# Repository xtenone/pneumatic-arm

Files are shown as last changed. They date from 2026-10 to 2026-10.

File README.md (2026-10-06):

# pneumatic-arm

An accessible robot arm that works with cylinders, like muscles, and is controlled with
feedback by a program or AI. Built from ordinary, widely available parts. The end goal
is an arm that picks up blocks of about 15 kg and builds a wall with them.

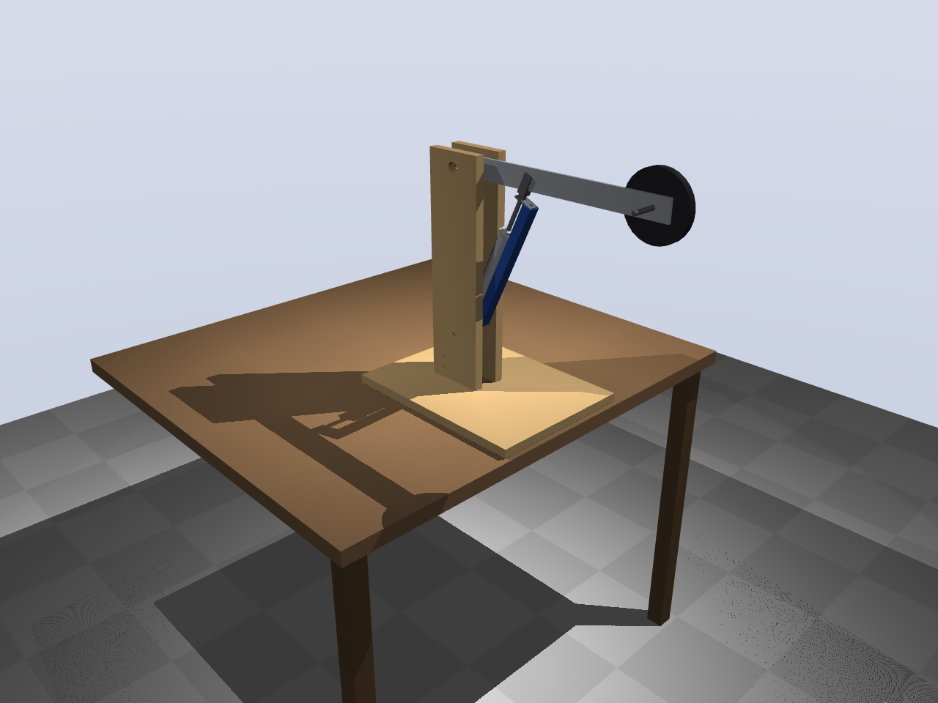
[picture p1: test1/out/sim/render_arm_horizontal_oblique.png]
Test 1


## Status

| Step | Status |
|---|---|
| Goal and requirements | [goal.md](goal.md) |
| **Test 1 — arm with one degree of freedom** | design, CAD, simulation, firmware and manual done; parts ordered, not built yet — [test1/](test1/README.md) |
| Test 1 reference — the same arm on a harmonic drive | sizing done — [test1-harmonic-drive/](test1-harmonic-drive/README.md) |
| Test 1 reference — printed cycloidal drive (PLA) | on hold; designed, STL ready — [test1-cycloid/](test1-cycloid/README.md) |
| 2-DOF joint (shoulder, elbow) | first analysis — [docs/2dof-joint.md](docs/2dof-joint.md) |
| Plan: what is done and what is left | [docs/plan.md](docs/plan.md) |
| Cost per degree of freedom | [docs/cost-per-dof.md](docs/cost-per-dof.md) |
| Full arm — concept render (layout and proportions) | first picture — [full-arm/](full-arm/README.md) |
| Full-size joint: 15 kg at 1 m (cylinders, speed, air) | first sizing — [docs/full-arm-sizing.md](docs/full-arm-sizing.md) |
| Hydraulics as an option (if more force is needed) | parts and prices — [docs/hydraulics.md](docs/hydraulics.md) |

## Build it yourself

Start at [test1/README.md](test1/README.md) and the
[manual](test1/docs/manual.md). All dimensions are in `test1/params.py`;
`python test1/build.py` regenerates the CAD, simulation, firmware settings, drawings and
bill of materials from it.

## Contributing

Questions, measurements, photos of your own build and improvements are welcome through
issues and pull requests. Measurements from tests T0–T7 are especially valuable: they
make the simulation model better.

## License

Copyleft: hardware under **CERN-OHL-S-2.0**, software under **GPL-3.0-or-later**.
See [LICENSE](LICENSE).

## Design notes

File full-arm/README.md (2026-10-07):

# Full arm — concept

A first picture of the complete arm, placing a 15 kg block on a low wall. Simple shapes
only, to show the layout and proportions; the sizes come from
[docs/full-arm-sizing.md](../docs/full-arm-sizing.md). The renders keep both rolls at 0 and
line the block up with the gripper's yaw motor (see "Choice for now"). Not a worked-out
design.

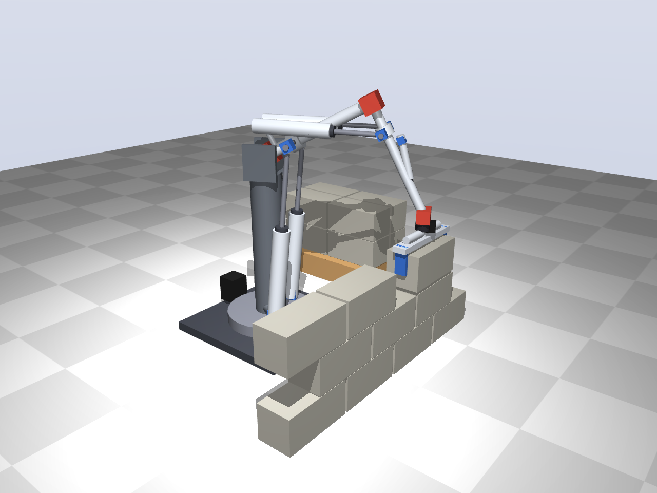
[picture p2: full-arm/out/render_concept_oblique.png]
Concept


## Layout

| Joint | DOF | Drive | Why |
|---|---|---|---|
| Base yaw | 1 | Electric: stepper with belt on a slewing ring | A vertical axis carries no gravity torque, so a small motor is enough, and it can turn further than the ≈ 120° of a cylinder |
| Shoulder | 2 (pitch + roll) | 2 × Ø50 × 300, lever 150 mm (Ø63 in the renders); the [test 2](../test2/README.md) joint at ≈ 1.7× scale | 162 Nm with 15 kg at 1 m (peak), 97 Nm at 0.6 m (work) |
| Elbow | 2 (pitch + forearm roll) | 2 × Ø40–50 lying on top of the upper arm, like a biceps; the same joint as the shoulder | see below |
| Wrist | 1 (pitch) | 1 small cylinder along the forearm | keeps the block level |
| Gripper | — | two jaws closed by a pneumatic cylinder | clamps the block at its ends |

- Upper arm and forearm 0.5 m each, shoulder 0.8 m above the floor, wall 0.6 m in front of
  the base: a low wall of 3 courses, about 1 m wide.
- Cylinders for the heavy joints, a small motor where there is no gravity torque.
- The base yaw axis runs through the shoulder joint, so turning the base does not move the
  shoulder. The column stands behind it on the turntable and turns with it; an arm over the
  top carries the shoulder joint, and the shoulder cylinders' lower pivots sit on a pin
  through the column. The forces of the shoulder cylinders stay inside the column, the
  arm and the upper arm; the arm and the column hanging behind the yaw axis partly
  balance the arm in front of it.

## Elbow: forearm roll instead of a wrist rotation (`python full-arm/elbow.py`)

The elbow uses the same 2-DOF joint as the shoulder. Its roll turns the forearm about its
own axis, as in a human forearm, so the gripper needs no separate rotation. With base
yaw, shoulder pitch + roll, elbow pitch + roll and wrist pitch the arm has 6 DOF: enough
to hold the block level and lined up with the wall.

Required for 9 block positions (3 along the wall, 3 courses), 15 kg block + 3 kg gripper:

| | Range |
|---|---|
| Base yaw | ±41° |
| Shoulder pitch / roll | −7° … +30° / ±20° |
| Elbow pitch | −101° … −64° (forearm steep) |
| Forearm roll | ±42° |
| Wrist pitch | 59° … 78° |
| Elbow cylinders, pin to pin | 454–582 mm (128 mm of stroke used) |
| Elbow cylinder force | ≤ 187 N push: 19% of Ø50, 30% of Ø40 at 5 bar |

- **Feasible.** The shoulder roll stays well within its ±65°; the forearm roll of ±42° just
  fits the ≈ ±45° the elbow allows (see the clash check below).
- The rolls grow with the base yaw: for a wall 1.2 m wide (base yaw ±42° at the ends of a
  wall 0.5 m away) the shoulder needs up to ±86° and the forearm ±69°, beyond the
  joint. For wider walls the base moves along the wall, or the gripper gets its own
  rotation about the vertical (a small motor; no gravity torque there).
- The cylinders lie on top of the upper arm (rear pivots 6 cm from the shoulder, 12 cm
  above the arm axis and 6 cm to the sides, clear of the shoulder hub and its cross
  blocks), on a forearm hub 12 cm from the elbow. A Ø50 × 200 (pin to pin ≈ 390–590 mm)
  covers the lengths.
- Ø40 is enough for the low wall (forearm steep). With the forearm horizontal the elbow
  needs up to ≈ 80 Nm, then Ø50.

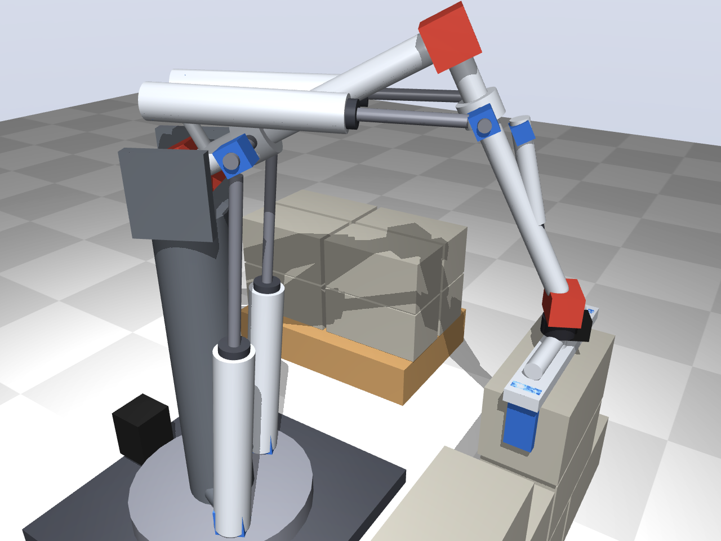
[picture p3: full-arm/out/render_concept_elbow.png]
Elbow


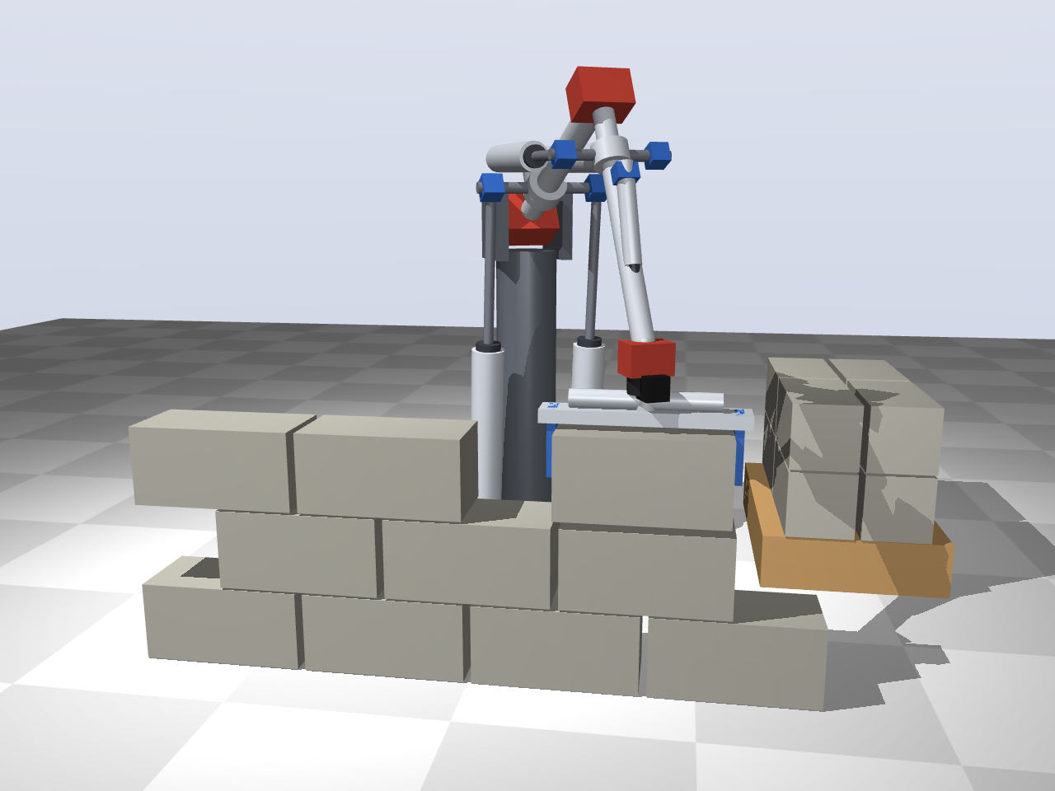
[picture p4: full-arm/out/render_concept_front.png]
Front


### Clash check (`python full-arm/elbow_cad.py`)

CadQuery model of the elbow region in the upper-arm frame: upper arm with the shoulder hub
and its cross blocks, the post with the rear U-joints, the elbow fork and yoke, the forearm
hub with cross blocks, and the two cylinders with rod forks.

| Elbow pitch | Roll 0° | Roll ±42–45° | Roll ±65° |
|---|---|---|---|
| −110° | ok | rod fork touches the forearm hub | many clashes, too short |
| −100° | ok | ok at ±42°, rod fork touches the hub at ±45° | cylinder bodies on the upper arm and shoulder hub |
| −90° … −64° | ok | ok | cylinder bodies on the upper arm and shoulder hub |
| −50° | ok | stroke too short | stroke too short, clashes |

- **The low wall works:** its whole range (pitch −101° … −64°, roll ±42°) is clash-free and
  within the stroke.
- **But the margin is small.** The forearm roll of this layout ends at about ±45°, not the
  ±65° of the shoulder: when rolling, one cylinder dives onto the upper arm and the rod fork
  comes close to the forearm hub.

### Biceps or triceps

The same checks for the cylinders behind the elbow: the forearm shaft sticks out 10 cm
behind the elbow through the joint, with cross blocks 8 cm to the sides; the cylinders lie
high on top of the upper arm and pull that lever, like a triceps or the stick cylinder of
an excavator (`python full-arm/elbow.py triceps`, `python full-arm/elbow_cad.py triceps`).

| | Biceps | Triceps |
|---|---|---|
| Hub on the forearm | 12 cm in front of the elbow | 10 cm behind the elbow |
| Rear pivots | 6 cm from the shoulder, 12 cm up, 6 cm to the sides | 2 cm from the shoulder (post leaning back over the shoulder yoke), 13 cm up, 8 cm to the sides |
| Cylinders | Ø50 × 200 | Ø40 × 200 (shorter: the hub is closer to the rear pivots) |
| Low wall: force | ≤ 187 N push (19% of Ø50) | ≤ 197 N pull (37% of Ø40, 24% of Ø50) |
| Clash-free with roll ±45° | elbow bend 60°–90° (±42° up to 101°) | elbow bend 45°–105° |
| Roll ±65° | cylinder bodies dive onto the upper arm and shoulder hub | only the rod forks touch the small hub at the end of the lever |
| Arm almost straight (bend 30°) | ok | the lever behind the elbow hits the upper arm |

- **Triceps gives the forearm roll more room.** The cylinders never cross the elbow, so they
  cannot dive onto the upper arm when rolling; what is left at ±65° is the hub at the end
  of the lever, which is a detail.
- **Costs of the triceps:** the cylinders pull (smaller annulus area, so Ø50 rather than
  Ø40 once the forearm has to be held horizontal), the forearm shaft has to pass through
  the elbow joint, and the arm cannot be stretched straight.

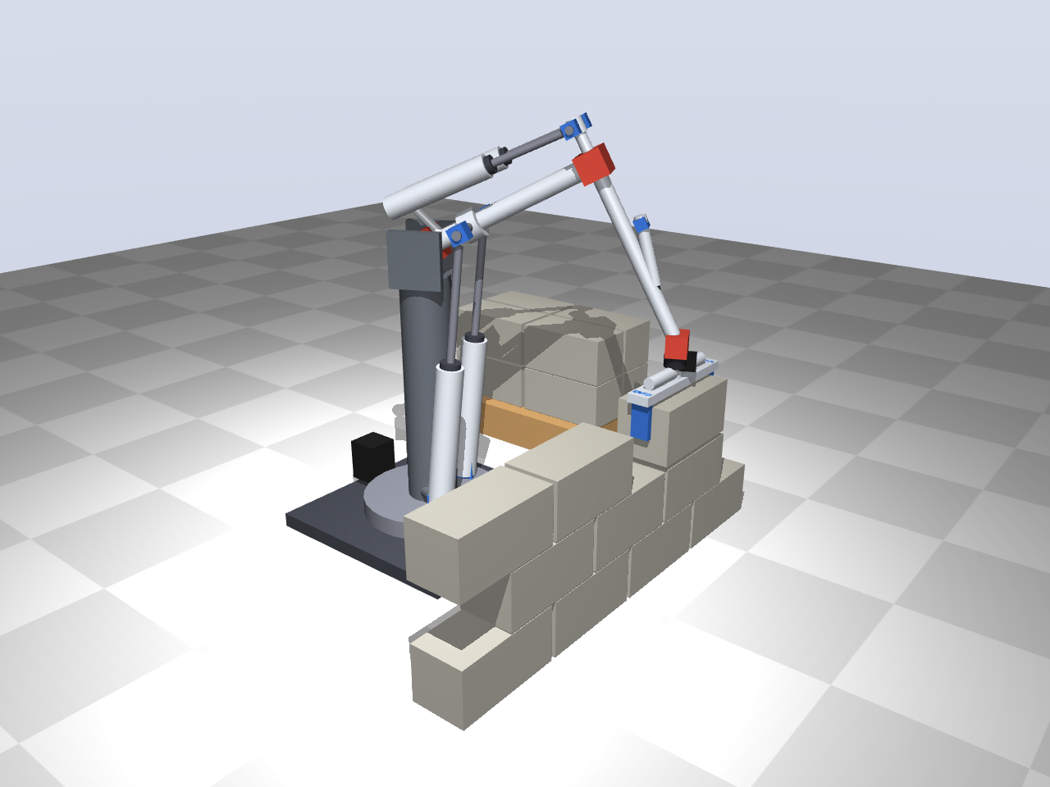
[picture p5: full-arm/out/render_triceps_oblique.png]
Triceps


### Arm turned over: elbow below the shoulder (`python full-arm/elbow.py triceps_down`)

Like a human arm: the upper arm hangs down from the shoulder, the forearm points forward,
and the cylinders behind the upper arm push the lever behind the elbow to lift. Shoulder
at 0.8 m, same low wall.

| | Elbow up, biceps | Elbow down, triceps pushing |
|---|---|---|
| Elbow cylinders | push, ≤ 187 N (19% of Ø50) | push, ≤ 400 N (41% of Ø50): the forearm reaches forward, so the elbow carries more |
| Shoulder pitch | −7° … +30° (the test 2 shoulder layout) | −78° … −49°: the shoulder cylinders need a different layout |
| Shoulder torque | up to 162 Nm (arm stretched forward) | ≤ 128 Nm (upper arm hangs) |
| Block lined up with the wall | 9/9 positions with rolls ≤ ±60° | 3/9: only straight ahead; at ±0.3 m the shoulder roll needs up to ±84° |

- With the forearm roughly horizontal, the forearm roll tilts the block instead of turning
  it. Lining the block up then has to come from the shoulder roll (as the human shoulder
  does), and that needs more than the ±65° of the cross block joint.
- Elbow down therefore needs a gripper that turns about the vertical (a small motor, no
  gravity torque there), or a base that moves along the wall. The forearm roll then tilts
  the tool, which is useful for wiping.

## Holding a glass

A lighter job for the same arm: holding a glass of water just above a table (rolls at 0,
the gripper's yaw motor keeps the jaws square to the arm). Shoulder pitch 64°, elbow −90°.

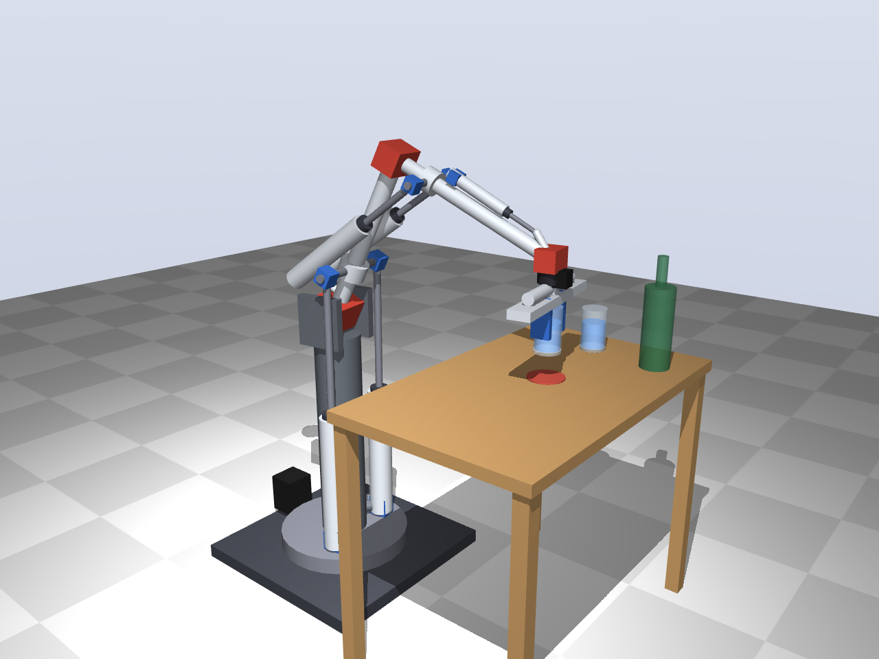
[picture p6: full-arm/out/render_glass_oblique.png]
Glass


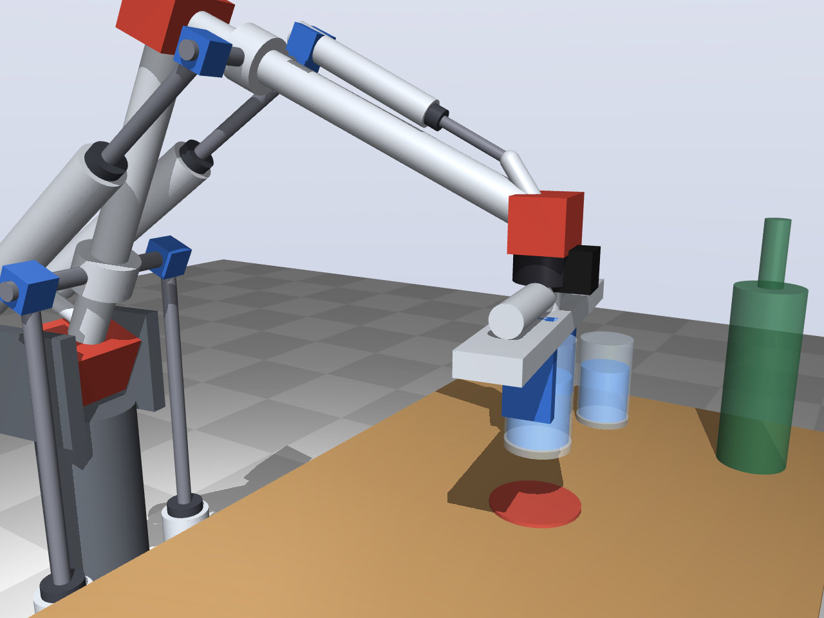
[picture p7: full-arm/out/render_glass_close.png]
Glass, close


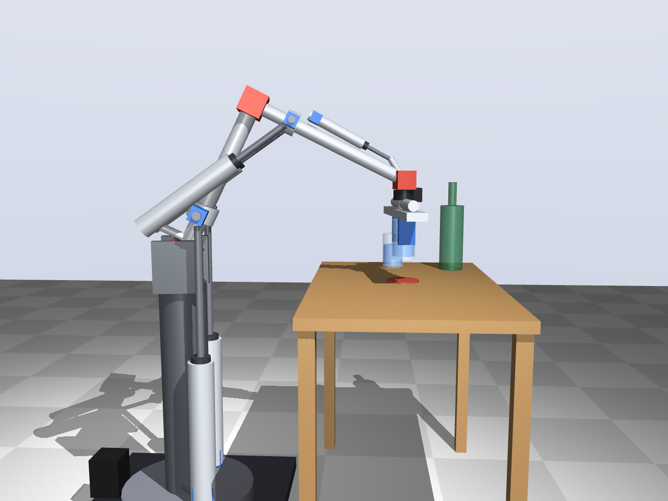
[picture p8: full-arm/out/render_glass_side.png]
Glass, side


The same with the upper arm hanging down (shoulder at 1.15 m, elbow cylinders behind the
upper arm, 60 mm from it and 20 cm from the shoulder: compact Ø50 × 100 cylinders, 22–30 cm pin
to pin, pushing a 9 cm lever behind the elbow; elbow range 10–90°). Render only; the shoulder cylinders are
still drawn in the test 2 layout, which does not suit this posture.

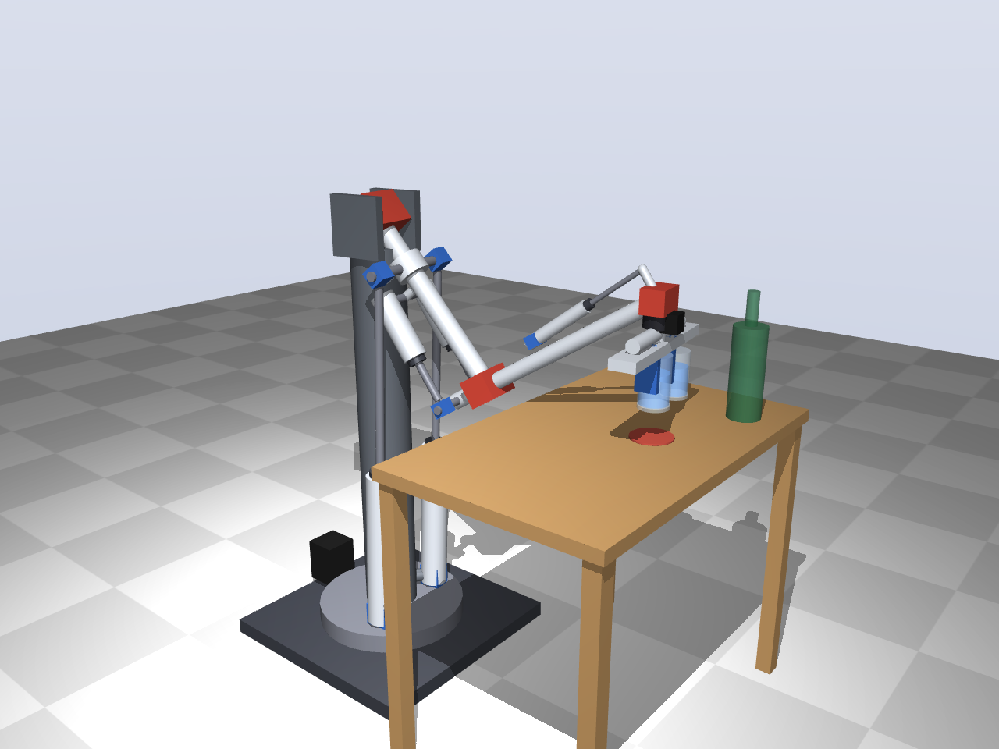
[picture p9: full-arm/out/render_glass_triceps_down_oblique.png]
Glass, upper arm down


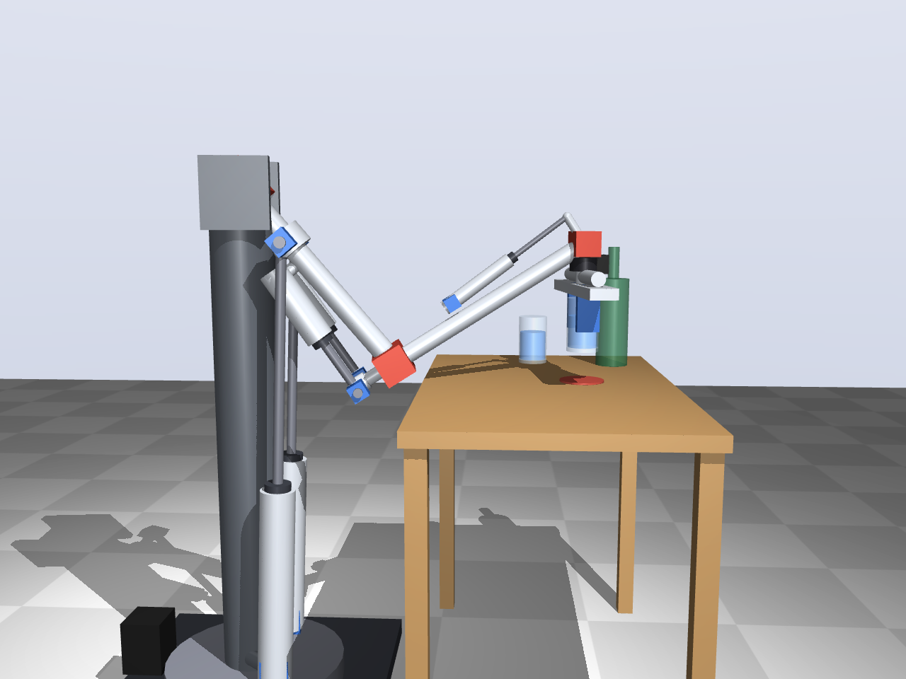
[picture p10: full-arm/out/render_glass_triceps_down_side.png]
Glass, upper arm down, side


## Cocktail impression (`python full-arm/cocktail.py`)

A light version of the arm (upper arm hanging, shoulder at 1.28 m; Ø25 × 80 elbow cylinders
beside the upper arm on a 5 cm lever, elbow 10–120°; wrist and gripper turned by small
motors) makes a cocktail: three bottles poured into a glass, stirred with a bar spoon, glass
slid forward. Kinematic only, 49 s; the video is not kept in git (`--stills` for frames).

The shoulder cylinders lean back to the column behind the shoulder on purpose: they push a
hub 15 cm along the upper arm, and the lever they act on is that line, not the vertical.
Over the video (upper arm −91° … −52°) their lever is 121–150 mm, largest where the arm
reaches furthest forward and gravity pulls hardest; peak force about 124 N. Cylinders
standing vertically under the shoulder would be nearly in line with the hanging upper arm:
lever 31–137 mm, peak force about 330 N.

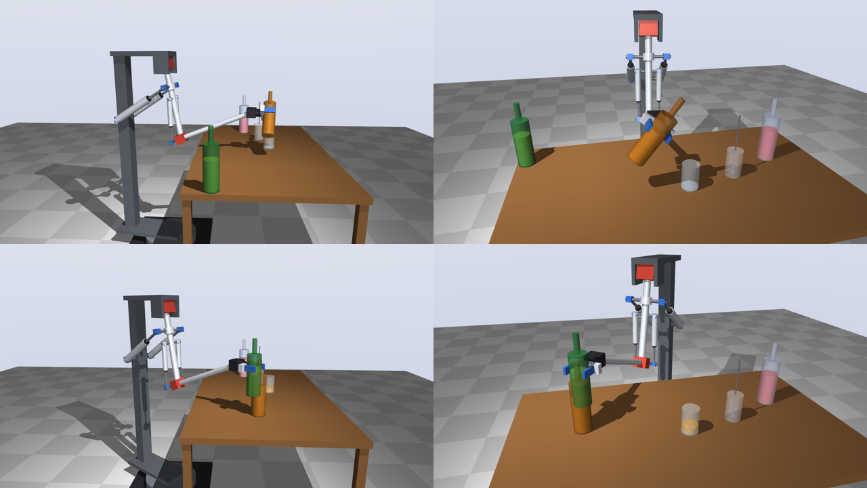
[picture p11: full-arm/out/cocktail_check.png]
Cocktail


## Small wall: start of stage 1 (`python full-arm/small_wall.py`)

The intermediate goal of [docs/small-wall.md](../docs/small-wall.md): the light arm
(shoulder 0.66 m above the table, 2 × Ø32 on a 100 mm lever) with four wooden blocks in a
corner jig and the taped places of the row against a stop strip. The gripper points down
(wrist motor) and is the proposed parallel gripper. `--check` lists the joint angles of
every pick and place: elbow bend 83–101°, base yaw −70° … +22°, shoulder cylinders
248–267 mm pin to pin with a lever of 94–99 mm.

`--video` renders stage 1a (speeds of the heavy arm: 58 s, about 14 s per block) and
`--video --fast` stage 1b (light arm's own speed: 25 s, about 6 s per block). Kinematic
only; the videos are not kept in git.

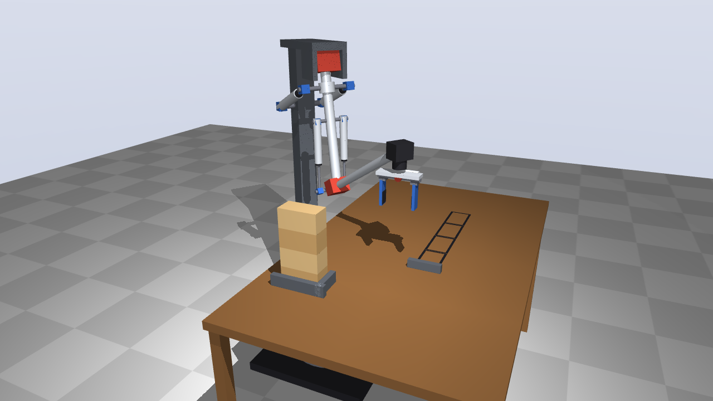
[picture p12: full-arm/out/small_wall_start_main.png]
Small wall, start


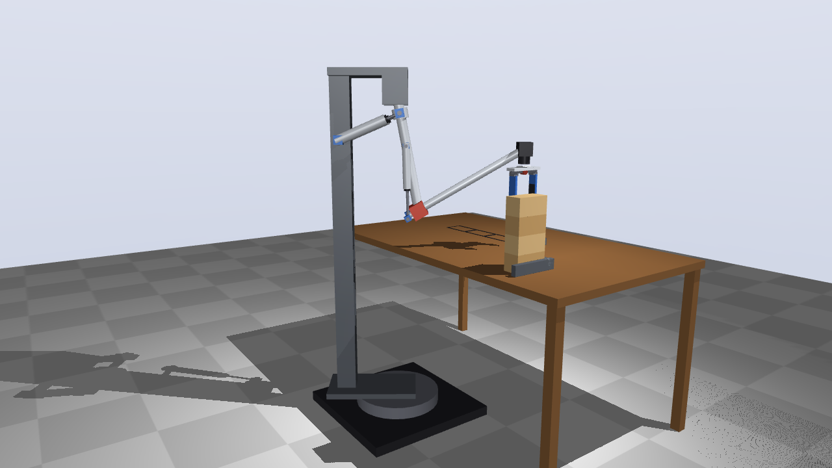
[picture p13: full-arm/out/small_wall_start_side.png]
Small wall, start, side: column behind the shoulder


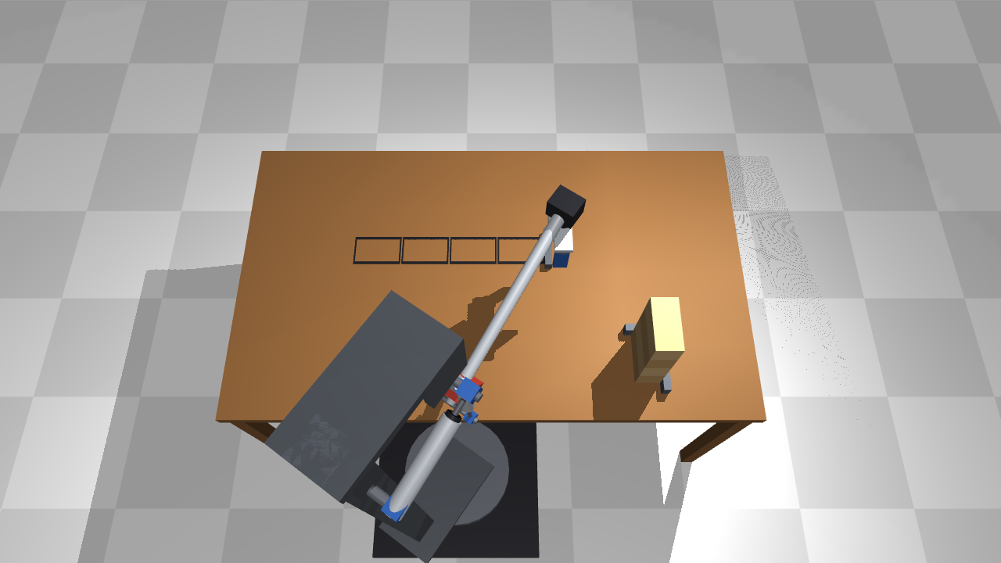
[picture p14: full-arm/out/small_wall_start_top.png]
Small wall, top


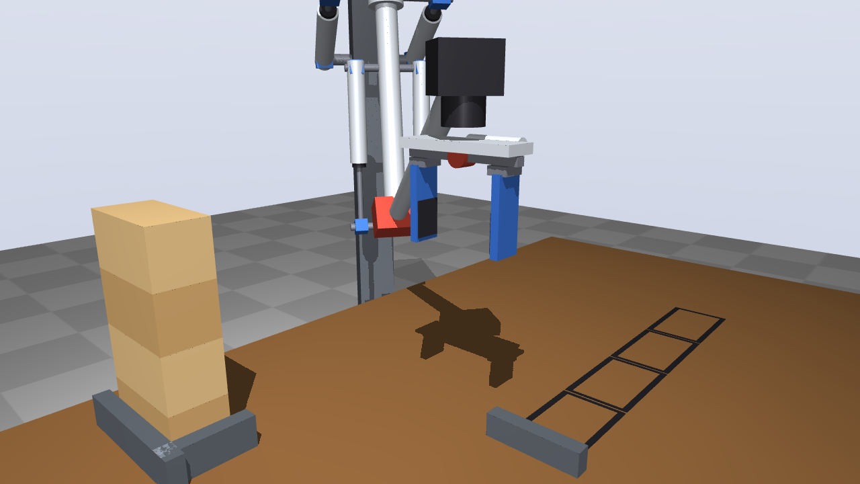
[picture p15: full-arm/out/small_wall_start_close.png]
Small wall, gripper


### Dynamic simulation (`python full-arm/arm_sim.py`)

The same stage 1 with a physical arm: MuJoCo for the links and the block, the test 1
pneumatics model (ISO 6358 flow, chamber pressures, VQ110U valves with switching times)
for the shoulder and elbow cylinders, and the test 1 controller for each of those joints
with its own gains. Base yaw and wrist are stiff motor servos. Before gripping or releasing,
the program waits until the gripper is within ±3 mm of its target and nearly still.
Results in [out/sim/results.md](out/sim/results.md):

| Case | Stage 1 time | Waiting | Lag while moving | Placement error |
|---|---|---|---|---|
| 0.3 kg, fast | 24.5 s | 4.3 s | 39 mm | ≤ 3 mm |
| 1.5 kg, fast | 23.8 s | 3.6 s | 44 mm | ≤ 3 mm |
| 3 kg, elbow 2 × Ø25, fast | 33.8 s | 13.6 s | 195 mm | up to 11 mm |
| 3 kg, elbow 2 × Ø32, retuned, fast | 31.0 s | 10.8 s | 289 mm | up to 19 mm |
| 1.5 kg, controlled | 53.5 s | 3.4 s | 16 mm | ≤ 3 mm |
| 3 kg, elbow 2 × Ø32, retuned, controlled | 56.8 s | 6.7 s | 15 mm | ≤ 3 mm |

- **Up to 1.5 kg the load hardly matters:** about 24 s fast (plan 20.2 s), placement
  within 3 mm.
- **3 kg at the fast speeds is beyond the arm.** The air springs of shoulder and elbow
  carry the arm at only 1.0–1.6 Hz (effective mass at the rod 100–460 kg); with 3 kg the
  arm lags 0.2–0.3 m behind the plan, swings at the end of a move, waits up to the 3 s
  limit and sometimes places a block 1–3 cm off. A larger elbow cylinder (Ø32) and
  retuned gains help only a little.
- **3 kg at the controlled speeds works:** 57 s instead of 54 s, placement within 3 mm.
- So for heavier blocks the arm either moves slower, or it needs the compensation of
  stage 1b: feedforward of gravity and acceleration, so that the cylinders already push
  when the move starts instead of after an error has built up.
- The numbers are as good as the model: the pneumatics model and the friction estimates
  are checked against the real cylinder in test 1 (T1–T3). No contacts are simulated (a
  block that is placed too low would in reality hit the table).

`--tune` runs step tests; `--video N` renders case N of `CASES` with the planned gripper as
a green ghost (MP4 not kept in git).

## Choice for now

- **Elbow above the shoulder, biceps layout (cylinders pushing).** The test 2 shoulder
  carries over as it is, the forearm hangs steeply so the elbow forces stay low (Ø40–50),
  and the elbow stays high, out of the way of the wall. Excavators are built this way for
  the same reasons.
- **Gripper turns about the vertical with a small motor.** Lining a block up with the wall
  is then one simple, stiff axis with no gravity torque, instead of two soft pneumatic roll
  joints that both have to move. The shoulder and forearm rolls stay for dexterity
  (tilting a tool, the toilet task), not for lining up blocks.
- **Wrist kept level:** a small cylinder for now; a parallelogram linkage that keeps the
  gripper level by itself (as on palletising robots) is an option to look at.
- **Triceps and elbow-down stay documented as alternatives** (above).
- **The light version (1.5 kg) is built first,** with light wall blocks and speeds capped to
  those of the heavy version; see [docs/plan.md](../docs/plan.md#first-complete-arm-the-light-version).
- **The full arm stays a concept until test 1 has its results.** Test T7 sets how much of
  the cylinder force the control can use; that number sets every cylinder size here.

## Open

- Reach: with 2 × 0.5 m the arm builds a low wall from one spot; more needs a longer arm
  or a base that moves.
- Gripper for blocks versus a tool mount for light tasks.
- Base: fixed, on a pallet with counterweight, or on wheels.

`python full-arm/concept.py [triceps] [glass]` renders the views into `out/` (the first version is in
`out/archive/`).

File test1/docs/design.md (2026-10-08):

# Test 1 — design: arm with one degree of freedom, one cylinder, four fast valves

This document explains what was chosen and why. How to build and test it is in
[manual.md](manual.md); all dimensions are in `../params.py`.

## What this test has to prove

Can an ordinary pneumatic cylinder with cheap on/off valves and a microcontroller move
an arm to a chosen angle and keep it there, also with a load on it? And how precisely?
Each cylinder chamber gets its own pressure sensor. That lets the software control the
stiffness as well as the position: how hard the cylinder pushes back when you pull on it.

## The idea

A double-acting cylinder has two chambers, A (rod out) and B (rod in). Each chamber
gets two valves:

- a **fill valve**: when open, air flows into the chamber;
- a **vent valve**: when open, air flows out of the chamber.

When both valves of a chamber are closed, the air stays in. The valves open and close
tens of times per second (PWM). By keeping them open longer or shorter, the software
controls how fast a chamber fills or empties.

```
compressor ── filter + regulator ── shut-off slide ── main valve ──┐
                                                                   │
                                 ┌─────────────────────────────────┤
                                 │                                 │
                            [V1 fill A]                       [V3 fill B]
                                 │                                 │
      pressure sensor pA ── chamber A ═══ CYLINDER ═══ chamber B ── pressure sensor pB
                                 │                                 │
                            [V2 vent A]                       [V4 vent B]
                                 │                                 │
                              silencer                          silencer

             linear potentiometer along the rod ── position x
```

| V1 | V2 | Chamber A |
|----|----|---|
| off | off | holds pressure |
| on | off | fills |
| off | on | empties |
| on | on | **forbidden**: blows air straight through. The software blocks this. |

V3 and V4 work the same way for chamber B.

## The valves

**Choice: SMC VQ110U (large flow), 5 pieces: 4 plus 1 spare.**

- 3/2 valve, direct operated (poppet), normally closed
- Response time: on 3.5 ms, off 2 ms. Fast enough for PWM at 20–50 Hz.
- Maximum 0.7 MPa (7 bar), 24 V DC
- Small, and available on AliExpress
- Flow: Cv 0.02 (standard) or 0.04 (VQ110U, large flow)

| | Standard (VQ110) | Large flow (VQ110U) |
|---|---|---|
| Full stroke of the Ø20 cylinder, roughly | 0.5–1 s | 0.25–0.5 s |
| Smallest force step per pulse (approx. 4 ms) | 1–2 N | 3–4 N |

All four positions get a VQ110U. A cylinder is as fast as the slowest valve in the
loop: in every move one chamber fills while the other empties, so one standard valve in
that loop slows down the whole move. With four large valves the cylinder is fast in both
directions. The larger force steps (3–4 N) are expected to stay below the seal friction
(5–10 N), which limits the precision anyway.

To mimic a smaller valve, a flow restrictor can be put in series with each fill valve.
Turned in, the fill valve behaves like a smaller valve, continuously adjustable. This
measures which flow gives the best balance between speed and precision, and that
measurement drives the valve choice for the arm.

A 3/2 valve becomes a 2/2 valve by plugging one port with an M5 blanking plug:

- **Fill valve:** P ← supply, A → chamber, R plugged. Off = closed, on = filling.
- **Vent valve:** P ← chamber, A → silencer, R plugged. Off = P closed, on = venting.

The leak test (T0) checks that the closed position really stays closed.

**Order code** (from SMC's "How to order" chart):

- `U` = large flow type
- `5` = 24 V DC (`6` = 12 V DC; `1`–`4` are AC)
- `M` or `L` = plug connector *with* lead wire; `MO`/`LO` = without lead wire
- `-M5` = single valve on a sub-plate with M5 ports. Without `-M5` it is a valve for a
  manifold, and you need a base for it.

Order code used: **VQ110U-5M-M5** (5×).

The cheaper version without `-M5` (manifold valve) does not fit here. A manifold has a
common P port for all valves, while the vent valves need their own P, because that is
where the chamber is connected.

Two manifolds do not solve that either: a fill block of VQ110s with the common R plugged
and a vent block of VQ120s (normally open) with the common P plugged. With all valves
off, chambers A and B are both connected to that plugged common channel, and therefore
to each other. The pressures equalise and the cylinder sags. Every valve needs its own
plugged port, which only a sub-plate per valve gives.

**How a coil reaches 50 Hz.** The VQ110 is *direct operated*: the coil lifts a small,
light armature a few tenths of a millimetre, and that armature is the valve itself. Large
valves such as the 4V210 are *pilot operated*: the coil opens a small air passage and
that air moves a large spool, which takes 20–50 ms. At 50 Hz one period is 20 ms, and the
VQ110 needs about 5.5 ms to open and close again. That fits easily.

There are two kinds of PWM:

- **Slow (20–50 Hz), which this set-up uses.** The valve follows every pulse: fully
  open, fully closed. The cylinder and tubes act as a buffer and average the bursts, like
  a bucket filled with short splashes. The pulse width sets the average flow.
  - A pulse shorter than the opening time (approx. 3.5 ms) does not open the valve. At
    50 Hz roughly 20–85% duty is usable. The software compensates for this dead zone.
  - A lower frequency gives finer steps but more pressure ripple. T1 sets the frequency.
- **Fast (kHz) on the coil.** The valve does not follow this; the coil averages the
  current. It is used for "peak and hold": full current to open, less to hold open. Less
  heat, and the valve closes faster. It does **not** hold an on/off valve half open; only
  a proportional valve can do that, and it is built differently (spool against a spring).
  Not needed for now.

The `M`/`L` variants have a built-in LED and surge suppressor, so polarity matters: red
to +24 V, black to an output of the ULN2803A.

**Service life.** At 50 Hz a valve switches 180,000 times per hour, but only while the
arm moves; at rest the valves are closed. Not a concern for the test. For the arm, valve
life becomes a selection criterion.

**Why not a cheaper 2/2 valve?** Ordinary solenoid valves such as the 2V025 and the 2W
series (€5) respond in 20–50 ms. PWM above about 10 Hz is then impossible and the control
gets coarse. The small 10 mm "high-frequency" valves are cheap (€5–8) but rated for 30 Hz
with very little flow: usable for a first test, not for an arm joint.

**Why not the VT307?** Also SMC, direct operated, with much more flow and "universal
porting" (pressure allowed on any port, so the same valve works as normally closed,
normally open or diverter). But its response time is about 20 ms, more than five times
slower than the VQ110, which limits PWM to about 10 Hz: too coarse for this control. For
the arm it is a candidate as a *coarse* valve for fast moves next to a small fast valve
for fine control.

**Looking ahead:** the VQ110 is big enough for this Ø20 test cylinder, not for the
cylinders of the final arm. Those will be Ø40–63, because 15 kg at arm's length needs
hundreds to over a thousand newtons of cylinder force. They need larger fast valves, or
several valves in parallel. This test provides the control software and the measurements
to make that choice.

## Parts

The current list with items, variants, quantities and prices is in
[order-list.json](../../docs/order-list.json); `tools/order_list.py` turns it into a
clickable page, and `build.py` turns it into [bom.md](bom.md).

Summary:

- **Pneumatics (AliExpress):** 5× VQ110U-5M-M5, cylinder MAL20×150 (PT1/8 ports) with an
  M22×1.5 nut and an M8 rod clevis, AFR-2000 regulator with fibre filter, HSV-08 shut-off
  slide, 3V210-08 main valve (NC, 24 V DC), emergency stop in a box, 4 mm push-in
  fittings (M5, 1/8, 1/4), PCF4-02 for the pressure sensors, 4 mm tees, M5 blanking plugs,
  M5 silencers, 2 flow restrictors, 10 m of 4×2.5 mm PU tube.
- **Sensors (AliExpress):** KTC linear potentiometer 175 mm (5 kΩ, type B), 2 pressure
  sensors 0–100 psi G1/4 (output 0.5–4.5 V or 0–5 V; the 10k/15k divider is safe for both).
- **Electronics:** ULN2803A (AliExpress, 10 pieces); Pico 2, LM7805C, 1 µF and 100 nF
  capacitors, 10 kΩ and 15 kΩ resistors, breadboard, DC jack, USB cable and wire; a 24 V
  adapter.
- **DIY store:** plywood, aluminium flat bar and strip, 608 bearings, M8 bolts, tube for
  spacer sleeves, hose clamps, F-clamps, plug nipple to match the compressor, tube cutter,
  PTFE tape, and a multimeter if needed.
- **Compressor:** Stanley DST 100/8/6, 6 l, 8 bar, 59 dB (quiet enough for indoor testing).

EU import duty (since 1 July 2026): €3 + VAT per product category per consignment. Items
shipped by AliExpress itself are grouped into categories.

**Why not an optical distance sensor (VL6180X, VL53L series)?** It measures without
contact, which is attractive. But the VL6180X is rated up to 100 mm while the stroke is
150 mm, its noise is a few millimetres against a target of ±1 mm, and one measurement
takes about 10 ms: at 0.6 m/s the cylinder has moved 6 mm before the reading arrives. Too
slow for a fast control loop.

## Pneumatic connections

Each row is one connection; the quantities in the parts list follow from this.

**Supply**

| From | Fitting | Tube | To | Fitting |
|---|---|---|---|---|
| Compressor hose (Euro coupler) | – | – | regulator IN | plug nipple G1/4 + PTFE tape |
| Regulator OUT | – | – | shut-off slide IN | male thread of the slide straight into the regulator (otherwise PC4-02 + tube + PC4-02) |
| Shut-off slide OUT | PC4-02 | 4 mm | main valve P | PC4-02 |
| Main valve A | PC4-02 | 4 mm | 4 mm tee | – |
| Main valve R | leave open (only vents the supply line on an e-stop) | – | – | – |
| Tee branch 1 | – | 4 mm (later via a flow restrictor) | V1 P (fill A) | PC4-M5 |
| Tee branch 2 | – | 4 mm (later via a flow restrictor) | V3 P (fill B) | PC4-M5 |

**Per chamber (A with V1/V2, B with V3/V4)**

| From | Fitting | Tube | To | Fitting |
|---|---|---|---|---|
| Fill valve, port A | PC4-M5 | 4 mm | tee 1 | – |
| Tee 1 | – | 4 mm | vent valve, port P | PC4-M5 |
| Tee 1 | – | 4 mm | tee 2 | – |
| Tee 2 | – | 4 mm | cylinder port | PC4-01 |
| Tee 2 | – | 4 mm | pressure sensor | PCF4-02 |
| Vent valve, port A | M5 silencer | – | – | – |
| Port R of fill and vent valve | M5 blanking plug | – | – | – |

- **Short tubes:** keep every tube between valves and cylinder shorter than about
  30 cm, and put the pressure sensor close to the cylinder port.
- **Flow restrictors:** if the restrictor has an arrow (one-way type), point it towards
  the fill valve. Fully open, it does not restrict the flow.

**Threads**

- G1/8 and G1/4 are BSP threads (also sold as PT or BSPT on AliExpress). They fit each
  other; use PTFE tape on PT.
- **Do not buy NPT:** NPT has a different pitch (27 instead of 28 threads per inch) and
  jams or leaks in a G port. Watch out with pressure sensors in particular; they are often
  sold with 1/8 NPT.
- M5 is M5×0.8 everywhere.
- **Tube:** everything in 4 mm (4×2.5). During a move only one fill valve is open
  (approx. 40 Nl/min), and 4 mm tube is ample for that.
- **Import duty:** €3 + VAT per product category per consignment, so the design keeps
  the number of different parts low: no 6 mm tube and no Y-piece.

## Electrical

- **Pico 2 → ULN2803A:** 4 PWM pins, one per valve. The ULN2803A switches the low side
  of each coil. A VQ110 coil draws only about 40–60 mA, well within the chip's 500 mA
  per channel. The flyback diodes are inside the chip: pin 10 (COM) to +24 V.
  - A diode slows down the closing of the valve a little. If that shows up in T1, a
    Zener diode per coil will be added.
- **Coils:** red to +24 V, black to an output of the ULN2803A. Mind the polarity: the
  built-in LED and suppressor work in one direction only.
- **Emergency stop and main valve:** the +24 V from the adapter goes through the
  emergency stop first. After it come the main valve (directly, so it is on whenever the
  e-stop is released) and the plus of the four VQ110U coils. Pressed: everything drops
  out, even if the software hangs.
- **Potentiometer:** on the Pico's 3.3 V, wiper to ADC0 (GP26).
- **Pressure sensors:** on 5 V from an LM7805C fed from the 24 V, not on the USB 5 V.
  - The output of these sensors scales with their supply voltage. The USB voltage varies
    up to ±5%, which would directly give ±5% measurement error.
  - The two sensors draw about 20 mA together; the 7805 then dissipates
    (24 − 5) V × 0.02 A ≈ 0.4 W, fine without a heat sink. A linear regulator gives a
    quieter supply than a switching step-down, which is better for analogue readings.
  - Capacitors: 1 µF between IN and GND, 100 nF between OUT and GND, close to the pins.
  - The 7805 sits before the e-stop, so the sensors keep measuring when the e-stop is
    pressed.
  - Each sensor output goes through a 10 kΩ (top) / 15 kΩ (bottom) divider (or 3× 47 kΩ in
    parallel = 15.7 kΩ, ratio 0.61, 5 V → 3.05 V) to ADC1 (GP27)
    and ADC2 (GP28). That turns 5.0 V into 3.0 V, safe for the Pico whether the sensor
    gives 0.5–4.5 V or 0–5 V.
  - Which output type it is shows at the first reading: at 0 bar it gives about 0.5 V or
    about 0 V. The software calibrates at 0 bar and at a known pressure (the regulator's
    gauge).
- **Noise:** a 100 nF capacitor from each ADC input to GND.
- **Ground:** the adapter's minus, pin 9 (GND) of the ULN2803A and the Pico's GND
  connected together.
- **PC over USB:** powers the Pico and receives the data (position, two pressures,
  valve states), hundreds of times per second.
- **Supply:** a closed 24 V plug-in adapter (at least 0.5 A, 1–2 A preferred), no open
  mains supply with screw terminals, so there is no 230 V anywhere near the rig.
  Consumption: 4 valve coils at most ~250 mA, main valve ~125 mA, 7805 + sensors ~25 mA;
  about 400 mA in the worst case.

## Mechanical: the arm

The cylinder lifts an arm, as it will in the shoulder. This tests what happens in the
real arm: a force that changes with the angle, a load at the end, and the conversion from
cylinder length to angle. See `out/drawings/side_view.pdf`.

- **Upright:** two 18 mm plywood cheeks with a 36 mm spacer block between them (two
  layers of the same plywood), on a 40 × 30 cm base plate. The rig sits on the edge of a
  table, held by two F-clamps; the arm end with the load sticks out beside the table.
- **Hinge:** an M8 bolt through two 608 ball bearings (skateboard bearings) in the
  cheeks, 420 mm above the base plate. Cheap, available everywhere, and without play.
- **Arm:** aluminium flat bar 40×5 mm, 450 mm long. The cylinder's clevis attaches
  150 mm from the hinge; the load, 1 kg dumbbell plates on an M8 bolt, sits at 400 mm.
  Bolted on, it cannot swing (a hanging bottle would set the arm swinging), and the
  gripper of the real arm also holds its load firmly.
- **Cylinder:** pivots at the rear on an M8 bolt, 320 mm straight below the hinge.
  Pin-to-pin 311–461 mm gives an arm angle of −17° to +66°.
- **Potentiometer:** fixed to the cylinder tube with hose clamps, its rod connected via a
  small bracket to the cylinder rod. It measures the cylinder length; the software
  converts that to the angle.

| Arm angle | Cylinder lever | Max. torque at 5 bar | Gravity (arm + 1 kg) | Load |
|---|---|---|---|---|
| −17° | 148 mm | 23.2 Nm | 4.3 Nm | 18% |
| 0° | 136 mm | 21.3 Nm | 4.5 Nm | 21% |
| 40° | 85 mm | 13.4 Nm | 3.4 Nm | 26% |
| 66° | 43 mm | 6.7 Nm | 1.8 Nm | 27% |

The higher the arm, the smaller the cylinder's lever: the same effect as in the 2-DOF
joint later (see `docs/2dof-joint.md` in the repository root).

## Control

The algorithm is in `firmware/control.py` and runs **unchanged** on the Pico and in the
simulation, so the tuning from the simulation is exactly what goes onto the Pico.

**Layers:**

- **Fast layer, on the Pico (250 times per second):** reads position and pressures and
  drives the valves.
  1. **Speed-limited target:** the target moves to the requested position at most
     250 mm/s. A full stroke takes about 0.6 s, without a step in the control error.
  2. **Position controller (PID) → desired force.**
     - The integral term only works close to the target (within 6 mm) or when the arm is
       stalled. That overcomes friction and load without overshoot.
  3. **Force → chamber pressures:** the desired force is split over chambers A and B, with
     the sum of both pressures as the **stiffness** (adjustable, default 4 bar).
  4. **Pressure loop per chamber → PWM duty:** fill, vent or hold. Filling and venting the
     same chamber at the same time is impossible. A minimum pulse length makes sure the
     valve really opens.
  5. **In position:** error < 0.3 mm, the arm is still and the pressures are at their
     targets. Then all valves close and the trapped air holds the arm. This saves air and
     valve wear; control resumes above 0.6 mm.
  6. **Relief:** if a chamber goes above 6 bar (e.g. air compressed when overshooting),
     that chamber's vent valve opens. If it lasts longer than 0.5 s, a fault follows: the
     regulator is set too high.
- **Slow layer, on the PC (program or AI):** sends the target angle and stiffness, and a
  `ping` every 0.2 s. If the Pico misses it for half a second, all valves close.

**Loop speed, measured on the Pico 2 W:** a step (read the sensors, control, set the
valves, a data line every second step) takes about 2 ms; 500 Hz did not fit, so the loop
runs at 250 Hz. A data line costs 0.5 ms with `%` formatting (1.6 ms when every field is
turned into text separately). About 1.5 times per second MicroPython's memory clean-up
stops the loop for 8–12 ms; the valves keep their PWM, and the next step uses the real
elapsed time, so the speed estimate does not jump. The simulation includes these pauses.
`info` shows how many steps took too long.

For holding and for the steps of T3 no feedforward is needed. The delays in the loop are
small: valve 2–3.5 ms, a pressure wave through 30 cm of tube about 1 ms, and filling a
chamber tens of ms.

**Fast and smooth (T8, mode `move`):** the speed-limited target of step 1 starts and stops
with a jolt, and the controller only pushes once an error has built up: on the moves of
T8 the arm lags up to 21 mm behind and overshoots up to 9 mm. Mode `move` replaces step 1
and adds to step 2:
- **Profile of the arm angle:** a quintic from the current state to the target, so
  position, speed and acceleration are continuous. Planned in degrees, not in cylinder
  length: near the top the cylinder's lever is small and the same acceleration in mm
  would need four times the force. Limits: speed 170°/s, acceleration 1550°/s², and a
  limit on the jerk, because the valves need time to swap the pressures. These keep 10%
  margin in time: about 1.1× as fast still passes in the simulation, 1.15× does not. A new target
  during a move starts a new profile from the current speed and acceleration.
- **Feedforward:** force = (gravity torque + inertia × planned angular acceleration) /
  lever, plus the seal friction in the direction of motion. The PID only corrects what is
  left; its D term works on the difference between planned and measured speed.
- The load must be known (the number of 1 kg plates); the arm's own mass and inertia
  come from `params.py`.
- A heavier load gets a lower speed, not different tuning: with 2 kg the move to 50° only
  settles in time at 80% speed.

## Simulation

`sim/run.py` simulates the arm in MuJoCo with a model of the pneumatics:
- valve flow according to ISO 6358
- valve opening and closing delays
- chamber pressures, seal friction
- sensor noise and ADC steps

Results with the current tuning (`out/sim/results.json`, plots in `out/sim/`):

| Test (simulation) | Result |
|---|---|
| T3 without load, `gain 0.5` | 0° → 30° and 30° → −5°: overshoot ≤ 1.7 mm, settled in 0.5–0.6 s — passed (in 1 of 3 noise runs; the others settle in 1.1–1.4 s or overshoot 4 mm, without shaking) |
| T3 without load, `gain 1` | shakes at about 7 Hz, ±6 mm: the tuning for 1 kg is too strong for the bare arm |
| T3 step 0° → 30° (1 kg) | overshoot 1.5 mm, error 0.3 mm, but within ±1 mm only after 1.5 s — not passed |
| T3 step 30° → −5° (1 kg) | overshoot 2.6 mm, settled in 0.7 s, error 0.2 mm — passed |
| T2 on/off control (3 bar) | stays 13–24 mm off target: PWM control is needed |
| T6 stiffness (one plate added, valves closed) | 9.8° deflection at 2 bar chamber pressure, 6.7° at 5 bar |
| T7 load | target reached up to 3 kg (68% load); within 1 s at 2 kg, at 1 and 3 kg just too slow; at 4 kg 11 mm short |
| T8 fast and smooth (preset angles) | 30° in 0.40 s, largest move (−5° → 50°) 0.58 s; follows the profile within 2.5 mm, overshoot ≤ 1.6 mm. Settling: in 1 of 3 runs one move is within ±1.5 mm only 0.32 s after the profile (limit 0.2 s). 2 kg: passes at 80% speed |

The weak point is the last millimetre, not the speed: after a move the arm wanders about
±1–1.5 mm before it comes to rest (pressure dead band and seal friction), so the
settling criteria of T3 and T8 pass or fail by chance. A lower speed does not change
this (checked). The real rig shows how large dead band and friction really are; the
holding behaviour is improved after that.

Exact numbers per run: [`../out/sim/results.md`](../out/sim/results.md).
The tuning belongs to the load: without load the arm needs half the gains (`gain 0.5`),
at 1 kg the full ones; T7 shows the same upwards. The arm will probably need tuning
that scales with the load or the position.

The model is an estimate. Friction, dead volumes and the flow of these valves are measured
in T1–T4; after that the model is updated and the control re-tuned.

## Tests

Tests T0–T8, with criteria, are in [manual.md](manual.md), section 11.
`host/tests_t0_t8.py` runs them and assesses them with the same analysis as the
simulation (`host/analysis.py`).

## Safety

- **Pressure:** start at 2–3 bar and never go above 6 bar (the valves' limit is 7 bar).
- **Shut-off slide:** within reach. Closing it depressurises the supply line, but not
  the cylinder chambers: their air is trapped behind closed valves.
- **Emergency stop:** cuts the 24 V to all valves. All fill and vent valves close, so the
  cylinder keeps its air and does not sag. The main valve closes and vents the supply. If
  a fill valve sticks, no more air comes in.
- **At every start-up:** wear safety glasses, keep your hands away from the rod and the
  bracket, and secure the tubes. A tube that comes loose whips around.
- **Software:** closes all valves on a fault, at start-up and when USB contact is lost.
  With all valves closed the cylinder keeps its air.
- **Depressurising the cylinder:** first close the shut-off slide, then open vent valves
  V2 and V4, from the software or with the manual override button on the valve itself.
  Only then work on the rig.
- **Arm:** keep your hands out from between the arm and the upright. Clamp the base plate
  to the table edge with two F-clamps; the loaded arm end sticks out beside the table.
- **Relief:** above 6 bar the software opens that chamber's vent valve.
- **Pneumatics are not harmless:** Ø20 at 6 bar pushes almost 19 kg, and the arm's
  cylinders will be many times stronger. The arm's safety has to come from the design:
  limited pressure, limited speed and compliance. The medium alone does not make it safe.

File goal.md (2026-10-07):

# Goal

Steps 1–4 of the stepwise method this project follows: a goal in plain words, the
approach, a concrete target, and a one-sentence presentation that makes it testable.
Each step is the cheapest way to answer a question before taking the next, more
expensive one (text → drawing → simulation → physical test).

## 1. Goal

Build an accessible robot arm: made from commonly available parts, and controlled with
feedback by a program or AI. It does not need industrial speed or precision: half of
what a human arm can do is enough.

## 2. Approach

The joints are moved by cylinders or linear actuators, the way muscles move a human arm,
instead of by motors with gearboxes in the joint. Pneumatics is the first candidate:
compressed air gives way in a collision, and the force can be limited by the pressure.

A simple test rig proves first that a cylinder can be controlled with feedback. Joints
are then added step by step, starting with a two-degree-of-freedom (2-DOF) joint moved
by cylinders.

## 3. Target

An arm that picks up blocks and stacks them into a wall.

## 4. Presentation

A home-built, cylinder-driven arm picks up blocks of about 15 kg and builds a wall
with them.

On the way there, the arm first does light tasks to practise and to show what it can do;
the first is cleaning a toilet (see [docs/plan.md](docs/plan.md)).

Intermediate goal with the light arm (1.5 kg): a small wall of wooden blocks, first a row
from a stack, then two courses in running bond (see [docs/small-wall.md](docs/small-wall.md)).

## Requirements

- Payload: about 15 kg per arm.
- Safety: a fault must not cause a dangerous blow; force and speed must be limited.
- Parts can be bought normally (web shops, AliExpress): no special industrial motors or
  custom drives.

## Open questions

- Reach and accuracy of the arm: how far must it reach, and how precisely must a block be
  placed?
- Keep the cost of the test rigs as low as possible.

## Status (updated when it changes)

The full plan with what is done and what is left: [docs/plan.md](docs/plan.md).

- **Test 1 (arm with one degree of freedom: one cylinder, 4 fast valves with PWM)**:
  complete package in [test1/](test1/README.md) (CAD, simulation, firmware, manual, bill
  of materials); design in [test1/docs/design.md](test1/docs/design.md). AliExpress parts
  ordered on 2026-10-04, electronics and compressor on 2026-10-05; DIY-store parts still to buy. Order list:
  [docs/order-list.json](docs/order-list.json).
- **2-DOF joint**: sketch and first analysis in [docs/2dof-joint.md](docs/2dof-joint.md);
  not yet worked out.

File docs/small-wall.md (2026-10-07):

# Intermediate goal: a small wall of wooden blocks

The light arm (1.5 kg at 1 m, see [full-arm-sizing.md](full-arm-sizing.md#light-version-15-kg-at-1-m))
takes blocks from a stack and lays them in a row, and then in a small wall of two
courses. It is the wall task of the [goal](../goal.md) at small scale: the same steps
(pick, turn, place, line up) with light, safe blocks.

## Blocks

| | |
|---|---|
| Material | Planed pine beam, nominal 70 × 70 mm (actual ≈ 68 × 68) |
| Full block | 68 × 68 × 136 mm (length = 2 × width), ≈ 0.3 kg |
| Half block | 68 × 68 × 68 mm (cube), ≈ 0.15 kg |
| Finish | All edges chamfered 2 mm, so a block slides into place instead of catching |

- **Why wood:** easy to saw to size with a mitre saw, cheap, square, and harmless when
  dropped. Length 2 × width allows a running bond, like bricks.
- **Why this size:** the gripper only needs one opening (68 mm across the block) for
  full and half blocks; at 0.3 kg the arm works at about a quarter of its load limit, so
  speed and accuracy can be tested without the load in the way.
- **Heavier later:** steel in a drilled hole brings a block to about 1 kg (stage 3).

## Layout on the table

```
          wall (start against a stop strip)
        ┌────┬────┬────┬────┐
        │    │    │    │    │          ← ≈ 0.53 m in front of the yaw axis
        └────┴────┴────┴────┘
                                    ┌──┐
              (arm base)            │  │ stack(s), ≈ 0.58 m from the yaw axis,
                 ●                  └──┘ about 70° to the side, turned 90°
                                         relative to the wall
```

- The base yaw axis runs through the shoulder joint; distances are measured from it.
- The shoulder is about 0.66 m above the table top, so the elbow stays at least 12 cm
  above the table.
- Stack: full blocks 4 high (0.27 m) in a corner jig, so their positions are known.
- Wall: 4 full blocks long (≈ 0.55 m), starting against a strip screwed to the table.
- Reach (2 × 0.5 m arm, `python full-arm/small_wall.py --check`): the elbow bends 85–89°
  at the wall and 83–101° at the stack, within its 10–120°. Further away the arm is more
  stretched and settles worse: in the simulation the stack at 0.67 m made the picks
  oscillate.
- No camera: the positions are fixed by the jig and the strip and known to the program.

## Joints used

| Joint | Drive | Task |
|---|---|---|
| Base yaw | Motor | Between the stack and the wall |
| Shoulder pitch | 2 × Ø32 | Reach and height |
| Elbow pitch | 2 × Ø25 | Reach and height |
| Wrist pitch | Motor | Keeps the gripper pointing straight down |
| Gripper yaw | Motor | Turns the block 90° from the stack to the wall |
| Gripper | Cylinder | Clamps the block across its 68 mm width |

The shoulder and forearm rolls are held at 0: both cylinders of a joint get the same
command.

## Gripper

Requirements:

- Two jaws gripping the 68 mm width from above, on the long faces of the block (these
  stay free in the wall), opening ≥ 95 mm (≥ 13 mm free on each side, more than the
  expected placement error).
- Self-centring: both jaws move together, so closing does not push the block sideways.
- Squeeze ≥ 40 N: friction 2 × 0.4 × 40 = 32 N (rubber on wood), about 3× the weight of
  a 1 kg block.
- About 0.3 kg, within the 1.1 kg budget for the wrist end.
- Detects a missed block.

Proposal: a parallel gripper built from ordinary parts.

| Part | |
|---|---|
| Guide | MGN12 rail, 150 mm, with two carriages, one per jaw |
| Synchronisation | Two printed racks on one printed pinion (module 1.5, 16 teeth, PETG): the jaws always move mirror-wise |
| Drive | One double-acting cylinder Ø16 × 25 with magnetic piston, on one jaw; pushing closes |
| Force | Ø16 at 5 bar pushes 100 N; through the pinion the squeeze is half: 50 N |
| Stroke | 20 mm per jaw: opening 95 mm, empty closed 55 mm |
| Missed block | Reed switch on the cylinder at the "closed empty" end |
| Jaws | Printed fingers with 2 mm rubber pads and a lead-in chamfer at the tips; they grip the upper 40 mm of the block, so they clear the course below |
| Valve | One plain 5/2 solenoid valve (4V110 type, 24 V): open/close only, no control valve |
| Cost | About €40 (rail €15, cylinder €10, valve €8, reed switch €3, fittings) |

The printed parts get fit allowances and a fit-test print first.

## Stages and success criteria

| Stage | Task | Success |
|---|---|---|
| 1a. Row, controlled | 4 full blocks from the stack in a row against the strip, at the speeds of the heavy version | 9 of 10 runs: every block within ±5 mm and ±3° of its place, joints ≤ 5 mm, nothing knocked over; ≤ 20 s per block |
| 1b. Row, fast | The same at the light arm's own speed | 9 of 10 runs, same tolerances; ≤ 10 s per block |
| 2. Small wall | 2 courses in running bond: 4 full blocks, then half + 3 full + half (2 stacks of full blocks, half blocks beside them) | 9 of 10 runs, same tolerances, the wall stays standing |
| 3. Heavier blocks | Stage 2 with blocks of about 1 kg | as stage 2 |

Speeds:

| | Base yaw | Shoulder | Elbow | Hand |
|---|---|---|---|---|
| Controlled (as the heavy version, see [plan.md](plan.md#first-complete-arm-the-light-version)) | 30°/s | 30°/s | 50°/s | ≈ 0.5 m/s |
| Fast (safety cap of the light arm) | 90°/s | 55°/s | 115°/s | 1 m/s |

- Rough time per block: controlled ≈ 13 s, fast ≈ 6 s (two moves between stack and wall,
  four short moves down and up, grip and release, settling). The limits in the table
  leave room for slower settling.
- In both runs the last few centimetres before placing may be slower; the tolerances are
  the same.
- Stage 1b is the test for compensating the swinging out (feedforward, trajectory
  shaping, braking early). Once it passes, the speed goes up further.
- Stages 2 and 3 run at the controlled speeds first.
- Every run is recorded (video + joint log), as for the other tests.

## Open

- Gripper: CAD of the proposal above, fit test, then build.
- Reach and layout check in simulation (positions of the stack and the wall).
- Simulation of stage 1 ([full-arm/README.md](../full-arm/README.md#dynamic-simulation-python-full-armarm_simpy)):
  up to 1.5 kg the fast run takes about 24 s with blocks within 3 mm; 3 kg needs the
  controlled speeds or feedforward compensation.
- Repeatability of the arm: tests T4 (test 1) and test 2 show whether ±5 mm is
  realistic at 0.65 m.

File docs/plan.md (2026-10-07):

# Plan

What is done and what is left. Updated: 2026-10-07.

Roles: **(B)** = build, buy, measure; **(D)** = design, software, documentation, review.

## Phase 0 — Goal ✅

- [x] Goal and requirements (15 kg per arm, build a wall, safe, ordinary parts) — [goal.md](../goal.md)
- [x] Actuation: cylinders, pneumatics as the first candidate
- [x] 2-DOF joint sketch and first analysis — [2dof-joint.md](2dof-joint.md)

## Phase 1 — Test rig design ✅

- [x] Principle: one cylinder, 4 fast 2/2 functions (fill/vent per chamber) with PWM — [test1/docs/design.md](../test1/docs/design.md)
- [x] Valves: SMC VQ110U (large flow), each on its own sub-plate (a manifold would connect the chambers)
- [x] Sensors: KTC linear potentiometer 175 mm, 2 pressure sensors G1/4
- [x] Electronics: Pico 2W, ULN2803A, LM7805C for the sensors, emergency stop that cuts the 24 V
- [x] Pneumatic connections, everything in 4 mm tube
- [x] Tests T0–T7 with measurable criteria
- [x] Cost per DOF — [cost-per-dof.md](cost-per-dof.md)

## Phase 2 — Purchasing (in progress)

- [x] AliExpress: valves, pneumatics, sensors, ULN2803A — ordered 2026-10-04 (B)
- [x] Electronics (Tinytronics): Pico 2W, LM7805C, capacitors, 10k + 47k resistors, breadboard, DC jack, USB cable, wire, jumper wires, headers — ordered 2026-10-05, received 2026-10-07 (B)
- [ ] Check the 24 V adapter: DC (not AC), at least 0.5 A, plug size (5.5/2.1 or 5.5/2.5) (B)
- [x] Compressor Stanley DST 100/8/6 (6 l, 59 dB) — ordered 2026-10-05 (B)
- [ ] DIY store, after the compressor: plug nipple G1/4 matching its coupler, tube cutter, PTFE tape, plywood, aluminium, bearings, bolts, multimeter if needed (B)

Order list: [order-list.json](order-list.json); `tools/order_list.py` turns it into a
clickable page.

## Phase 3 — Test 1 as a complete package ✅

- [x] Test 1 = arm with one degree of freedom (a cylinder lifts an arm with a load) — [test1/](../test1/README.md)
- [x] One parameter file (`test1/params.py`) for CAD, simulation, firmware and drawings
- [x] CAD (CadQuery): STEP, STL, DXF, GLB
- [x] MuJoCo simulation with a pneumatics model; control tuned, T3 passes in simulation
- [x] Firmware (MicroPython, Pico 2) and PC tools (logger, tests T0–T7), tested with simulated hardware
- [x] Drawings: side view, cheek, arm, wiring diagram, connection list, pneumatic diagram
- [x] Manual (incl. incoming inspection), design, bill of materials; bundle `dist/test1-package.zip`

## Phase 4 — Build (B, reviewed by D)

- [ ] Upright, arm on bearings, cylinder pivoting between upright and arm, potentiometer on the cylinder (manual 3–6)
- [ ] Pneumatics according to the connection tables; tubes between valve and cylinder < 30 cm
- [ ] Electronics on the breadboard; test without air first (valves click, sensors read)
- [ ] Safety: emergency stop, shut-off slide, start at 2–3 bar

## Phase 5 — Tests and measurements

- [ ] T0 leak test
- [ ] T1 valve response, choose the PWM frequency
- [ ] T2 on/off control
- [ ] T3 PWM control (0° → 30° → −5°)
- [ ] T4 repeatability
- [ ] T5 holding with load
- [ ] T6 stiffness
- [ ] T7 load ratio (how much of the static force the control can use)
- [ ] Comparison with flow restrictors: smaller flow versus speed and precision

## Phase 6 — Decide

- [ ] Does pneumatic feedback control work well enough for the arm? Based on T3–T7.
- [ ] If so: size the shoulder and elbow cylinders with the outcome of T7 (first estimate: [full-arm-sizing.md](full-arm-sizing.md))
- [ ] Choose valves for the large cylinders (flow, possibly coarse + fine)

## First complete arm: the light version

The first complete arm is the light version for 1.5 kg at 1 m (shoulder 2 × Ø32 × 200,
elbow 2 × Ø25 × 80; see [full-arm-sizing.md](full-arm-sizing.md#light-version-15-kg-at-1-m)).
Its forces are close to tests 1 and 2, so their results carry over directly. The heavy
version (15 kg) follows when the light arm works.

The wall is practised with light blocks (≤ 1.5 kg including the gripper margin), with the
speeds capped in software to what the heavy version would reach with one VQ110U per
chamber:

| Joint | Cap | Heavy version |
|---|---|---|
| Shoulder | 30°/s | 2 × Ø50, lever 150 mm |
| Elbow | 50°/s | 2 × Ø50, lever 100 mm |

This shows the tasks, the reach and the pace of the heavy arm. It does not show its
dynamics: a heavier load sags more under a pressure change and takes longer to stop,
so control settings do not carry over one to one. The load share is similar (light
shoulder 24% / 39%, heavy 33% / 55% for work / peak), so the control works in the same range.

Intermediate goal for the light arm: [a small wall of wooden blocks](small-wall.md) (row from a
stack, then two courses).

## After that

- Work out the 2-DOF joint (universal joint, ball joints, pilot-operated check valves
  against sagging when a tube breaks), first in simulation, then build it
- Angle sensors on the joints (e.g. AS5600) instead of linear potentiometers

## First demo task: cleaning a toilet

Before the heavy work, the working arm practises on light tasks that show what it can do.
The first is cleaning a toilet. The first runs are a rehearsal: the toilet is cleaned
beforehand and the sponge is dry, so the arm, the control and the recording can be
practised without water or dirt.

What the task asks of the arm:
- [ ] Reach into the bowl and under the rim: a wrist with enough orientations (at least
  pitch and rotation) and a slim forearm
- [ ] Constant, gentle contact force while wiping: with cylinders the chamber pressure
  sets the force, so force control comes almost for free
- [ ] Tool mount for a sponge or brush on the wrist
- [ ] Remote control by a person (joystick or a small leader arm the large arm follows),
  with recording of the movements and camera images
- [ ] Camera on or near the arm
- [ ] Later, with water and cleaning agent: splash-proof joints, sensors and wiring

After that: learn the task from the recorded runs (imitation learning) so the arm does it
by itself. Other candidate tasks: laundry from the washing machine to the dryer.

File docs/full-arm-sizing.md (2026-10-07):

# Full-size joint: 15 kg at 1 m

First sizing of the real arm joint, scaled up from the [test 2](../test2/README.md)
design: two cylinders standing under a hub on the arm, both out = pitch up, one out and
one in = roll. Range as test 2: pitch −60° … +75°.

The numbers come from `python tools/full_arm_sizing.py`. They are an estimate: the
outcome of test T7 (how much of the available force the control can use) sets the
final cylinder size.

## Requirement

| Case | Torque with the arm horizontal |
|---|---|
| 15 kg at 1 m, arm 3 kg (one 1 m segment) | **162 Nm** |
| 15 kg at 1 m, arm 30 kg (complete arm, estimate from [2dof-joint.md](2dof-joint.md)) | 294 Nm |

For comparison: test 1 delivers at most 21 Nm, test 2 (2 × Ø20 on a 90 mm lever) 28 Nm.

15 kg with the arm stretched is the limit, not the normal work: it happens rarely, briefly
and slowly. Normal work holds the 15 kg closer in, at about 0.6 m.

| Load case | Arm 3 kg | Arm 30 kg | Allowed share of the available torque |
|---|---|---|---|
| Work: 15 kg at 0.6 m | 97 Nm | 177 Nm | 40% |
| Peak: 15 kg at 1 m | 162 Nm | 294 Nm | 70% |

The peak may use more of the force because it is held still or moved slowly: the margin
for accelerating and for the control is small there. How long it lasts does not matter to
a cylinder: holding a force costs no air and nothing heats up (unlike a motor).

## Cylinders

Rule (first sizing, before the load cases above): the static load may use at most about 40% of the available torque (test 1 is
designed at 30–39%), at 5 bar, two cylinders pushing together.

The lever (hub distance from the joint) trades cylinder diameter against stroke: the
stroke for −60° … +75° is about 1.83 × the lever. The air used per movement is the same
for every choice; it follows from torque × angle.

**Arm 3 kg (162 Nm):**

| Lever | Cylinder | Stroke | Load |
|---|---|---|---|
| **150 mm** | **Ø63** | **300 mm** | **35%** |
| 250 mm | Ø50 | 500 mm | 33% |
| 370 mm | Ø40 | 700 mm | 35% |

**Arm 30 kg (294 Nm):**

| Lever | Cylinder | Stroke | Load |
|---|---|---|---|
| 150 mm | Ø80 | 300 mm | 39% |
| 250 mm | Ø63 | 500 mm | 38% |
| 370 mm | Ø63 | 700 mm | 26% |

Lever 150 mm keeps the joint compact, is the test 2 layout at about 1.7× scale, and
avoids long slender cylinders that buckle sooner. The joint then sits about 90 cm above
its base.

**With the load cases** (work ≤ 40%, peak ≤ 70%, lever 150 mm):

| Arm | Cylinder | Work load | Peak load | Speed work / peak (1 × VQ110U) |
|---|---|---|---|---|
| 3 kg | **Ø50 × 300** | 33% | 55% | 33 / 30°/s |
| 30 kg | Ø63 × 300 | 38% | 63% | 19 / 17°/s |

Choice for now: **lever 150 mm with Ø50 × 300** (Ø63 for the heavy arm), one size smaller
than with the 40% rule for the peak: about 1.5× faster and 37% less air per lift. If T7
shows that less than about 70% is usable at slow speed, the shoulder goes back to Ø63
(Ø80).

Roll is not limiting: at this size more than 200 Nm is available about the arm axis,
while a block hanging 10 cm beside the axis needs about 15 Nm.

## Speed

Steady speed lifting with the arm horizontal, flow model as in test 1 (ISO 6358). Filling
the piston side and venting the rod side both count; venting is often the limit.

| Valves per chamber | Arm 3 kg, Ø63 | Arm 30 kg, Ø80 | Valve effective area |
|---|---|---|---|
| 1 × VQ110U (test 1 valve) | 20°/s, 0.34 m/s at the tip | 12°/s, 0.21 m/s | 0.7 mm² |
| 4 × VQ110U in parallel | 78°/s, 1.4 m/s | 48°/s, 0.84 m/s | 2.9 mm² |
| 1 × 4V210-type 5/2 valve | not the limit (hoses, regulator, compressor are) | idem | ~14 mm² |

The speed hardly depends on the lever: a longer lever moves a thinner cylinder further.

- The test 1 valves give a slow but usable speed for placing blocks.
- Faster needs more flow. The large 5/2 valves are cheap but switch in 15–30 ms instead
  of 2–4 ms, so the control has to be adapted (for example coarse + fine valves).

### Speed per joint with the test 1 valve

With 1 × VQ110U per chamber the speed is set by the valve flow and the size of the
cylinder (bore × lever), and hardly by the load:

| Joint | Torque with 15 kg | With 15 kg | Without load |
|---|---|---|---|
| Shoulder, Ø50, lever 150 mm | 162 Nm | 30°/s | 33°/s |
| Shoulder, Ø63, lever 150 mm (40% rule for the peak) | 162 Nm | 20°/s | 20°/s |
| Elbow, Ø50, lever 100 mm (15 kg at 0.5 m) | 77 Nm | 49°/s | 50°/s |

**Decision:** the shoulder may be slow; it positions the arm. Fast movements (for other
work such as scrubbing) come from the elbow and the wrist, which have smaller cylinders
and are faster with the same valve. One VQ110U per chamber is therefore the starting
point. If the shoulder turns out to be too slow: 4 VQ110U in parallel or one larger,
cheaper valve per chamber.

## Air use

One full lift (−60° → +75°) with two cylinders Ø50 × 275 mm sweeps 1.1 l, about
**4 l of free air** at a chamber pressure of 3.5 bar absolute (Ø63: about 6 l, Ø80: about
10 l). One full lift every 5 s is about 45 l/min; to be checked against the compressor's
delivery.

## Light version: 1.5 kg at 1 m

A second version for most small tasks (glass, sponge, tools): 1.5 kg at the hand, upper
arm and forearm 0.5 m each, same joints. Here the arm's own mass weighs as much as the
load. Estimated masses: wrist pitch motor + gripper rotation motor + gripper 1.1 kg,
forearm 0.5 kg, upper arm 1.2 kg including the elbow cylinders.

| Joint | Peak (stretched) | Work (0.6 × peak) |
|---|---|---|
| Shoulder | 31.6 Nm | 19.0 Nm |
| Elbow | 13.4 Nm | 8.1 Nm |

Options (two cylinders per joint, 5 bar, same rules: work ≤ 40%, peak ≤ 70%):

| Joint | Cylinders | Lever | Peak load | Work load | Speed with the load / empty, 1 × VQ110U |
|---|---|---|---|---|---|
| Shoulder | 2 × Ø25 | 100 mm | 64% | 39% | 164 / 200°/s |
| Shoulder | **2 × Ø32 × 200** | **100 mm** | **39%** | **24%** | **118 / 119°/s** |
| Shoulder | 2 × Ø25 × 300 | 150 mm | 43% | 26% | 130 / 133°/s |
| Elbow | 2 × Ø20 | 75 mm | 57% | 34% | 374 / 417°/s |
| Elbow | **2 × Ø25 × 80** | **50 mm** | **55%** | **33%** | **366 / 400°/s** |
| Elbow | 2 × Ø25 × 125 | 75 mm | 37% | 22% | 265 / 267°/s |

Choice:

- **Shoulder 2 × Ø32 × 200 on a 100 mm lever:** the test 2 joint (2 × Ø20, 90 mm) with
  one size larger cylinders. Ø25 would just do, but leaves no room for errors in the mass
  estimate.
- **Elbow 2 × Ø25 × 80 on a 50 mm lever** (as in the cocktail impression, elbow 10–120°).
  The hand may become about 0.75 kg heavier before the peak reaches 70%.

Speed is no longer limited by the valve: the test 1 valve already gives more than 100°/s.
The limit becomes the control and safety. A cap of about 1 m/s at the hand means about
55°/s at the shoulder and 115°/s at the elbow. One VQ110U per chamber is plenty.

## Arm and joint

- **Arm:** aluminium tube Ø50 × 3 (6060). Bending stress below 70 MPa including 2× for
  acceleration; tip deflection with 15 kg about 6 mm.
- **Joint:** scales with the forces: shafts about Ø20 and proper bearings instead of bolts
  as pivots, bar and cross blocks at the hub about Ø20 / 30 mm.

## Open

- T7 result: usable load ratio at slow speed (≥ 70% → Ø50, otherwise Ø63) → final cylinder diameter.
- Valve choice for the large cylinders: 1 × VQ110U per chamber unless the shoulder proves too slow.
- Compressor delivery versus the air use above.
- Mass of the complete arm (elbow, forearm, gripper) → 3 kg or 30 kg case or in between.
- Light version: weigh the wrist motors and gripper → check the elbow margin.
- If much more force is needed: hydraulics with the same joint layout, see
  [hydraulics.md](hydraulics.md).

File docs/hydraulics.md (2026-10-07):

# Hydraulics as an option

For when the arm needs more force than pneumatics can give, or turns out to be too soft.
The joint layout stays the same (plain hinge, lever, a cylinder that only pushes), so the
joints, levers, sensors and control structure carry over; only the medium and the valves
change.

## When to consider it

- Forces much larger than the 15 kg arm (for example 50 kg or more, or heavy tools).
- Pneumatics too soft or not precise enough under load (tests T6 and T7).

For 15 kg at 1 m pneumatics is enough (Ø50–63 at 5 bar, see
[full-arm-sizing.md](full-arm-sizing.md)) and simpler, cleaner and safer.

## Comparison

| | Pneumatics | Hydraulics |
|---|---|---|
| Pressure | 5–6 bar | 50–200 bar |
| Force of a Ø20 cylinder | ≈ 160 N at 5 bar | ≈ 1600 N at 50 bar, ≈ 3100 N at 100 bar |
| Stiffness | air is a spring | oil hardly compresses: stiff, holds position under load |
| On a collision | gives way | does not give way |
| Control | pressure and flow, compressible | flow sets the speed, closer to a motor |
| Supply | compressor | power unit (motor, pump, tank, relief valve, accumulator) |
| Risks | low | oil leaks; a jet under high pressure can penetrate the skin |

A Ø20 hydraulic cylinder at 50 bar already carries the full-size shoulder (162 Nm on a
150 mm lever needs ≈ 540 N per cylinder), at the size of the test 1 cylinder.

## Valves (AliExpress, October 2026)

Proportional hydraulic valves are made in large numbers in China for agricultural and
construction machinery (mobile hydraulics), so they are much cheaper than pneumatic
proportional valves.

| Type | Price | Notes |
|---|---|---|
| Proportional cartridge valve, 2/2 (HydraForce SP08-20 type) | €90–115 | PWM current control; screwed into a manifold block (cavity VC08-2, 3/4-16 UNF). [SP08-20](https://nl.aliexpress.com/item/1005012186210270.html), [unbranded SP08-20](https://nl.aliexpress.com/item/1005009810937484.html) |
| Proportional pressure-reducing cartridge (HydraForce EHPR98 type) | ≈ €140 | sets a pressure per chamber (force control) |
| On/off cartridge valve, 2/2 poppet (Eaton/Vickers SV3-10-C type) | €35–60 | **not proportional**; switches in tens of ms, too slow and too harsh for PWM. Useful as a load-holding or safety valve. [SV3-10-C](https://nl.aliexpress.com/item/1005010718333141.html) |
| Proportional relief valve (Yuken EBG type) | ≈ €150 | sets the system pressure |
| Proportional directional valve NG6 (4WRA type) | ≈ €480 | one per cylinder, onboard electronics in some versions. [4WRA6E](https://nl.aliexpress.com/item/1005012391911557.html); original Rexroth via Chinese sellers €800–2000 |
| On/off directional valve NG6 (4WE6) | ≈ €67 | switches too slowly for PWM control |

Most promising: **four proportional cartridges per cylinder** in one block (fill and drain
per chamber, the same structure as the four VQ110U valves of test 1), about €400–500 per
cylinder including the block, or one proportional NG6 directional valve (≈ €480). Watch
the type code: many cartridges in the same family (SV…) are on/off valves, the
proportional ones are marked separately (SP…, EHPR…, EPV…). The Pico drives them with
a PWM current driver (MOSFET with current measurement).

Before buying an unbranded cartridge, ask the seller for:
- the type plate or datasheet (SP = proportional, SV = on/off; they look the same);
- coil voltage (12 or 24 V), maximum pressure and flow;
- the recommended PWM frequency (typically 100–300 Hz, often with dither);
- the flow direction it meters and the direction it blocks.

## System

| Part | Price (estimate) | Notes |
|---|---|---|
| Power unit: gear pump, continuous-duty motor, tank, relief valve | €400–800 | The cheap 12 V units (€140–300, e.g. [18 MPa](https://nl.aliexpress.com/item/1005012484978639.html)) are dump-trailer pumps for short duty, not for continuous control |
| Accumulator | | smooths the pressure, covers peaks |
| Filter (≈ 10 µm) | | proportional valves need clean oil |
| High-pressure hoses and fittings | | more expensive than pneumatic tube |
| Cylinders | Ø20–25 at 50–100 bar | small for the force |

## Points for the control

- Cheap cartridges have a dead band (spool overlap) and hysteresis; the controller has to
  compensate for them (dither on the PWM, dead-band compensation).
- Flow ∝ opening × √(pressure drop): the speed depends on the load, as with air, but
  without the spring of compressed air.
- Pressure sensors per chamber, as in test 1 (rated for the higher pressure).

## Safety

- Relief valve on the power unit, set to the lowest pressure that does the job.
- Hoses rated well above the system pressure, protected and fixed.
- Check valves (pilot-operated) on the cylinders so the arm does not drop when a hose
  breaks.
- Never feel for leaks by hand.
- Limit force and speed in software. The arm does not give way by itself.

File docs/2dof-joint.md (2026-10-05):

# 2-DOF joint with two cylinders

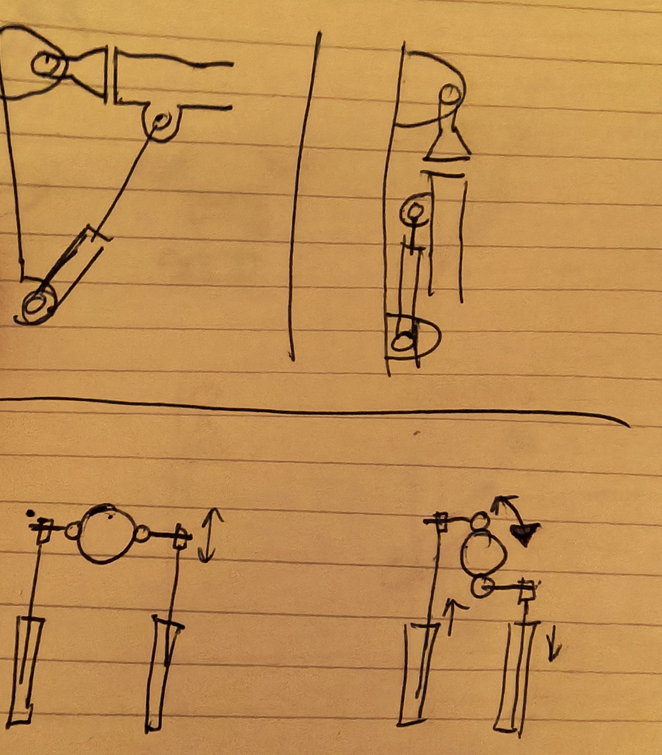
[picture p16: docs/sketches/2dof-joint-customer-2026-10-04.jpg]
Sketch


## The principle

A universal joint (cardan joint) in the middle carries the arm. On each side of the
middle there is a lever, and at the end of each lever a cylinder.

- **Both cylinders in the same direction:** the arm tilts up and down (pitch).
- **One cylinder out, the other in:** the arm rotates about the axis pointing away from
  the viewer in the bottom sketches (roll).

The same principle is used in the ankles and wrists of many humanoid robots: two linear
actuators side by side on a universal joint.

## Properties

- **For up and down the cylinders work together:** together they provide the torque
  against gravity, so the heavy axis gets the force of two cylinders.
- **Torque:** pitch = (F1 + F2) · r, roll = (F1 − F2) · b, where r is the distance from
  the pitch axis to the attachment points and b half the distance between the two
  attachment points.
- **Rotating under load:** the cylinders share the work. At maximum load for up and
  down, less is left for rotating.
- **Coupled, non-linear motion:** the software converts the desired angles into two
  cylinder lengths (inverse kinematics).

## What the design has to solve

1. **Centre joint:** a universal joint with intersecting axes. It carries all weight and
   all side loads of the arm, so it must be sturdy.
2. **Cylinder ends:** the attachment points move in three dimensions, so both ends of
   each cylinder need a ball joint or universal joint. Ordinary rod end bearings only
   allow about ±13–15° of misalignment. At larger angles they bind; then high-angle rod
   ends or small universal joints are needed.
3. **Leverage at the extremes:** torque is highest when cylinder and lever are at right
   angles and drops as they line up. The range of motion is chosen so they stay within
   about ±30–40° of perpendicular.
4. **No side loads on the rods:** the universal joint takes the side loads, not the
   cylinders.

## Holding position when a tube breaks

The cylinders must hold their position. Closed valves do that as long as the tubes stay
intact. If a tube between valve and cylinder breaks or comes loose, that chamber empties
and the arm sags with its load. The arm therefore gets pilot-operated check valves
directly on the cylinder ports. They only let air out of the chamber when pilot pressure
is applied; without it the air stays trapped in the cylinder. Not needed for the test rig.

## Holding position under a higher force (for later)

Closed valves hold the air, but air is springy. If an extra force pushes on the arm,
the air is compressed and the arm gives way, even if the valves stay perfectly closed. In
test 1 that is about 10° of deflection for 15 N extra on the load (simulation, 5 bar).
The pressure in the compressed chamber also rises, and the valves have to keep holding
it.

| Measure | What it does | Note |
|---|---|---|
| Higher chamber pressure (stiffness) | gives way less | limited by the weakest component (now 0.7 MPa) |
| Valves rated for higher pressure | stay closed during a pressure peak | fast direct-operated valves go up to about 8 bar, see below |
| Pilot-operated check valves on the cylinder ports | air cannot leave the cylinder, not even when a tube breaks | cheap; makes fine control harder |
| **Mechanical brake or rod lock** | the arm really stays put, independent of the air | e.g. a spring-applied disc brake on the joint, released by air: if air or power fails, it brakes |

Fast valves rated for higher pressure than the VQ110U:

| Valve | Max. pressure | Switching time | Note |
|---|---|---|---|
| SMC VQ110U (current) | 0.7 MPa | 3.5 / 2 ms | large flow (0.7 mm²) |
| SMC VQ110 high-pressure type | 0.8 MPa | ≤ 6.5 ms | smaller flow (0.3 mm²) |
| Festo MHE2 | 0.8 MPa | 1.7–2 ms, up to 330 Hz | more expensive; MHE3 has more flow |
| Ordinary 1 MPa solenoid valves (2V, 4V series) | 0.8–1.0 MPa | 20–50 ms | too slow for fine PWM; usable as a coarse valve |

Fast direct-operated valves above about 8 bar are rare. Really holding position under
overload is therefore more likely to come from a mechanical brake than from higher air
pressure.

## Shoulder force calculation (first rough estimate)

Assumptions: 15 kg at 1 m from the hinge, cylinders 50 cm long and attached at most
37 cm from the hinge, 5 bar, two cylinders pushing together with the full piston area.

| Case | Torque | Total force (lever 0.37 m) | Minimum Ø per cylinder |
|---|---|---|---|
| Weightless arm, 15 kg at 1 m | 147 Nm | 398 N | 2.3–2.4 cm |
| Plus a 30 kg arm with its centre of mass at 0.5 m | 294 Nm | 795 N | 3.2–3.4 cm |

This is the static lower bound: cylinder perpendicular to the lever, no acceleration,
no friction. A working control needs margin on top:

- **Lever at an angle:** the effective lever is 0.37 m · sin(angle between cylinder and
  lever). At 45° off the required force is 1.4× higher.
- **Control headroom:** to accelerate and brake, the static load may only use part of
  the available force. The back pressure in the other chamber and the pressure drop over
  the valves while moving also reduce the force. Test T7 measures how much margin is
  needed.
- **Rotating under load:** in roll one cylinder carries more than half.
- **Standard sizes:** Ø25, 32, 40, 50. With Ø40 the static load uses 63% of the
  available force (2× 628 N at 5 bar), with Ø50 40% (2× 982 N).

**Force versus range.** A long lever gives a lot of force but little angle per
centimetre of stroke. The angle is roughly stroke / lever (in radians): 20 cm of stroke
on a 37 cm lever gives about 30°. More angle needs a shorter lever and therefore a
thicker cylinder.

## Open questions

- Is "rotate" meant as rotation about the arm's own axis (like a wrist turning a key) or
  as swinging sideways (left–right)? The sketch shows the first. For swinging sideways
  the second axis of the universal joint has to be oriented differently.
- Desired range in degrees for up/down and for rotation. Together with the stroke this
  sets the lever length.
- Stroke of the 50 cm cylinders.
- Dimensions: lever lengths, and where the cylinders are attached at the bottom.

## Status

The joint is meant for both the shoulder and the elbow, with different cylinder sizes.
First force calculation for the shoulder above. Detailed design and simulation wait until
the test rig proves that pneumatics work.

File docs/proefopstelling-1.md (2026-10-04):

# Proefopstelling 1: één cilinder met vier snelle ventielen

## Wat deze proef moet bewijzen

Kan een gewone pneumatische cilinder met goedkope aan/uit-ventielen en een
microcontroller naar een gekozen positie gestuurd worden en daar blijven staan? En hoe
precies lukt dat? Elke kamer van de cilinder krijgt een eigen druksensor. Daarmee kan
het programma naast de positie ook de stijfheid regelen: hoe hard de cilinder
terugduwt als je eraan trekt.

## Het idee

Een dubbelwerkende cilinder heeft twee kamers, A (stang naar buiten) en B (stang naar
binnen). Elke kamer krijgt twee ventielen:

- een **vulventiel**: als het open is, stroomt er lucht de kamer in;
- een **leegventiel**: als het open is, stroomt er lucht uit de kamer naar buiten.

Zijn beide ventielen van een kamer dicht, dan blijft de lucht in die kamer zitten. De
ventielen gaan tientallen keren per seconde open en dicht (PWM). Door ze langer of
korter open te zetten, regelt het programma hoe snel een kamer vult of leegloopt.

```
compressor ── filter + drukregelaar ── afsluitschuif ── hoofdventiel ──┐
                                                                       │
                                     ┌─────────────────────────────────┤
                                     │                                 │
                                [V1 vul A]                        [V3 vul B]
                                     │                                 │
          druksensor pA ──── kamer A ═══════ CILINDER ═══════ kamer B ──── druksensor pB
                                     │                                 │
                                [V2 leeg A]                       [V4 leeg B]
                                     │                                 │
                                  demper                            demper

             lineaire potmeter langs de stang ── positie x
```

| V1 | V2 | Kamer A | 
|----|----|---|
| uit | uit | houdt druk vast |
| aan | uit | vult |
| uit | aan | loopt leeg |
| aan | aan | **verboden**: blaast lucht rechtstreeks weg. De software blokkeert dit. |

Voor kamer B gelden V3 en V4 op dezelfde manier.

## De ventielen

**Keuze: SMC VQ110U (grote doorstroming), 5 stuks: 4 plus 1 reserve.**

- 3/2-ventiel, direct bediend (poppet), normaal gesloten
- Reactietijd: aan 3,5 ms, uit 2 ms. Snel genoeg voor PWM op 20–50 Hz.
- Maximaal 0,7 MPa (7 bar), 24 V DC
- Klein, en op AliExpress verkrijgbaar
- Doorstroming: Cv 0,02 (standaard) of 0,04 (VQ110U, grote doorstroming).

| | Standaard (VQ110) | Grote doorstroming (VQ110U) |
|---|---|---|
| Volle slag Ø20-cilinder, ruwweg | 0,5–1 s | 0,25–0,5 s |
| Kleinste krachtstap per puls (ca. 4 ms) | 1–2 N | 3–4 N |

Alle vier de plekken krijgen de VQ110U. Een cilinder is zo snel als het langzaamste
ventiel in de lus: bij elke beweging vult de ene kamer en loopt de andere leeg. Eén
standaard ventiel in die lus remt de hele beweging. Met vier grote ventielen is de
cilinder in beide richtingen snel. De grotere krachtstappen (3–4 N) liggen naar
verwachting onder de wrijving van de afdichtingen (5–10 N), die de precisie toch al
begrenst.

Om toch een kleiner ventiel te kunnen nabootsen, komt er op elk vulventiel een
smoorventiel in serie. Dichtgedraaid gedraagt het vulventiel zich als een kleiner
ventiel, traploos instelbaar. Zo is te meten bij welke doorstroming snelheid en
precisie het best samengaan; die meting stuurt de ventielkeuze voor de arm.

Een 3/2-ventiel wordt een 2/2-ventiel door één poort dicht te draaien met een M5-blindplug:

- **Vulventiel:** P ← perslucht, A → kamer, R dicht. Uit = dicht, aan = vullen.
- **Leegventiel:** P ← kamer, A → demper, R dicht. Uit = P dicht, aan = leeglopen.

Bij de lektest (T0) controleren we of de dichte stand echt dicht blijft.

**Typenummer:** zoals ik de SMC-codering lees, betekent het volgende. Controleer het bij de verkoper:

- `-5` = 24 V DC
- `M` of `L` = stekker *met* kabel; `MO`/`LO` = zonder kabel, die varianten niet nemen
- `-M5` = losse klep op een aansluitblok met M5-draad. Zonder `-M5` is het een
  klep voor een ventieleiland, en dan heb je er nog een blok bij nodig.

Bedoeld typenummer: **VQ110U-5M-M5** (5×).

De goedkopere versie zonder `-M5` (los ventiel voor een ventieleiland) past hier niet.
Een ventieleiland heeft een gezamenlijke P-aansluiting voor alle ventielen. De
leegventielen hebben juist een eigen P nodig, want daar zit de kamer op.

Twee eilanden lossen dat niet op: een vulblok met VQ110's en dichte gezamenlijke R, en
een leegblok met VQ120's (normaal open) en dichte gezamenlijke P. Staan de ventielen
uit, dan zijn kamer A en kamer B allebei met dat dichte gezamenlijke kanaal verbonden,
en dus met elkaar. De drukken lopen gelijk en de cilinder zakt weg. Elk ventiel heeft
een eigen dichte poort nodig, en dat kan alleen met een eigen aansluitblok.

**Hoe een spoel 50 Hz haalt.** De VQ110 is *direct bediend*: de spoel trekt een klein,
licht ankertje een paar tienden van een millimeter op, en dat ankertje is zelf de klep.
Grote ventielen zoals de 4V210 zijn *voorgestuurd*: de spoel opent een klein
luchtkanaal en die lucht duwt dan een grote schuif om. Dat duurt 20–50 ms. Bij 50 Hz
duurt één puls 20 ms en heeft de VQ110 ongeveer 5,5 ms nodig om open en weer dicht te
gaan. Dat past ruim.

Er zijn twee soorten PWM:

- **Langzaam (20–50 Hz), wat deze opstelling doet.** De klep volgt elke puls: helemaal
  open, helemaal dicht. De cilinder en de slangen werken als buffer en middelen de
  stoten uit, zoals een emmer die je met korte scheuten vult. De pulsbreedte bepaalt
  hoeveel lucht er gemiddeld doorgaat.
  - Een puls korter dan de opentijd (ca. 3,5 ms) opent de klep niet. Bij 50 Hz is
    daardoor ruwweg 20–85% pulsbreedte bruikbaar. De software compenseert die dode
    zone.
  - Een lagere frequentie geeft fijnere stappen, maar meer drukrimpel. T1 bepaalt de
    frequentie.
- **Snel (kHz) op de spoel.** De klep volgt dit niet. De spoel middelt de stroom
  uit. Dit wordt gebruikt voor "peak-and-hold": vol aan om te openen, daarna minder
  stroom om open te houden. Dat geeft minder warmte en de klep gaat sneller dicht.
  Een aan/uit-klep kun je hiermee **niet** half open zetten; dat kan alleen een
  proportioneel ventiel, dat anders gebouwd is (schuif tegen een veer). Voor nu niet
  nodig.

Varianten `M`/`L` hebben een ingebouwd lampje en een overspanningsbeveiliging. Die zijn
gevoelig voor plus en min: rood aan +24 V, zwart aan een uitgang van de ULN2803A.

**Levensduur.** Bij 50 Hz schakelt een klep 180.000 keer per uur. Dat gebeurt alleen
tijdens bewegen; bij stilstaan zijn de kleppen dicht. Voor de proef is dit geen
probleem. Voor de arm wordt de levensduur een keuzecriterium bij de ventielen.

**Waarom geen goedkopere 2/2-klep?** Gewone magneetkleppen zoals de 2V025 en 2W-serie
(€5) reageren in 20–50 ms. Daarmee is PWM boven ongeveer 10 Hz niet mogelijk en wordt
de regeling grof. De kleine "hoogfrequente" miniventielen van 10 mm zijn goedkoop
(€5–8), maar opgegeven voor 30 Hz en met heel weinig doorstroming. Voor een eerste test
zijn ze bruikbaar, maar voor een armgewricht niet.

**Waarom geen VT307?** Ook SMC, direct bediend, met veel meer doorstroming en
"universele poorten": druk mag op elke poort staan, dus dezelfde klep kan als
normaal gesloten, normaal open of verdeelventiel gebruikt worden. Maar de reactietijd
is ongeveer 20 ms, ruim vijf keer trager dan de VQ110. PWM gaat daarmee tot ongeveer
10 Hz, te grof voor deze regeling. Voor de arm is hij wel een kandidaat als *grof*
ventiel voor snelle bewegingen, naast een klein snel ventiel voor de fijne regeling.

**Vooruitblik:** de VQ110 is groot genoeg voor deze proefcilinder (Ø20), niet voor de
cilinders van de uiteindelijke arm. Die worden Ø40–63, omdat 15 kg op armlengte
honderden tot meer dan duizend newton aan cilinderkracht vraagt. Daar komen grotere
snelle ventielen voor, of meerdere ventielen naast elkaar. Deze proef levert de
regelsoftware en de meetgegevens om die keuze te maken.

## Onderdelenlijst

De actuele lijst met artikelen, varianten, aantallen en prijzen staat in
[bestellijst.json](bestellijst.json). `tools/bestellijst.py` maakt daar een klikbare pagina
van in de gedeelde webmap (`hosted/pneumatic-arm/bestellijst.html`).

Samengevat:

- **Pneumatiek (AliExpress):** 5× VQ110U-5M-M5, cilinder MAL20×150 (poorten PT1/8) met
  2 voetbevestigingen, moer M22×1,5 en vorkkop M8, drukregelaar AFR-2000 met vezelfilter,
  afsluitschuif HSV-08, hoofdventiel 3V210-08 (NC, 24 V DC), noodstop in kastje,
  steekkoppelingen 4 mm (M5, 1/8, 1/4), PCF4-02 voor de druksensoren, T-stukken 4 mm,
  M5-blindpluggen, M5-dempers, 2 smoorventielen, 10 m PU-slang 4×2,5 mm.
- **Sensoren (AliExpress):** lineaire potmeter KTC 175 mm (5 kΩ, type B), 2 druksensoren
  0–100 psi G1/4 (uitgang 0,5–4,5 V of 0–5 V; de deler 10k/15k is voor beide veilig).
- **Elektronica:** ULN2803A (AliExpress, 10 stuks); Pico 2, LM7805C, condensatoren
  1 µF en 100 nF, weerstanden 10 kΩ en 15 kΩ, breadboard, DC-bus, USB-kabel en draad
  (Tinytronics); eigen 24 V-adapter.
- **Bouwmarkt:** insteeknippel G1/4 passend op de compressor, slangschaar, PTFE-tape,
  multiplex grondplaat, aluminium hoekje, eventueel een multimeter.
- **Compressor:** Parkside PSKO 248 B1 (Lidl), 24 l, 8 bar, 71,9 dB.

Invoerheffing (sinds 1 juli 2026): €3 + btw per productcategorie per zending. Artikelen die
AliExpress zelf verzendt, worden samen in categorieën ingedeeld.

**Waarom geen afstandssensor met licht (VL6180X, VL53L-serie)?** Die meet zonder
contact, en dat is aantrekkelijk. Maar de VL6180X is opgegeven tot 100 mm, de slag is
150 mm. De ruis is enkele millimeters bij een doel van ±1 mm. Een meting duurt ongeveer
10 ms: bij 0,6 m/s is de cilinder dan al 6 mm verder voordat de meting binnen is. Voor
een snelle regellus is dat te traag.

## Aansluitschema pneumatiek

Elke regel is één verbinding. De aantallen in de onderdelenlijst komen hieruit.

**Toevoer**

| Van | Koppeling | Slang | Naar | Koppeling |
|---|---|---|---|---|
| Compressorslang (Euro-koppeling) | – | – | drukregelaar IN | insteeknippel G1/4 + PTFE-tape |
| Drukregelaar UIT | – | – | afsluitschuif IN | buitendraad van de schuif direct in de regelaar (anders PC4-02 + slang + PC4-02) |
| Afsluitschuif UIT | PC4-02 | 4 mm | hoofdventiel P | PC4-02 |
| Hoofdventiel A | PC4-02 | 4 mm | T-stuk 4 mm | – |
| Hoofdventiel R | open laten (blaast alleen bij een noodstop de toevoerleiding leeg) | – | – | – |
| T-stuk tak 1 | – | 4 mm (later via smoorventiel) | V1 P (vul A) | PC4-M5 |
| T-stuk tak 2 | – | 4 mm (later via smoorventiel) | V3 P (vul B) | PC4-M5 |

**Per kamer (A met V1/V2, B met V3/V4)**

| Van | Koppeling | Slang | Naar | Koppeling |
|---|---|---|---|---|
| Vulventiel, poort A | PC4-M5 | 4 mm | T-stuk 1 | – |
| T-stuk 1 | – | 4 mm | leegventiel, poort P | PC4-M5 |
| T-stuk 1 | – | 4 mm | T-stuk 2 | – |
| T-stuk 2 | – | 4 mm | cilinderpoort | PC4-01 |
| T-stuk 2 | – | 4 mm | druksensor | PCF4-02 |
| Leegventiel, poort A | M5-demper | – | – | – |
| Poort R van vul- en leegventiel | M5-blindplug | – | – | – |

- **Korte slangen:** houd alle slangen tussen ventielen en cilinder korter dan
  ongeveer 30 cm, en zet de druksensor dicht bij de cilinderpoort.
- **Smoorventielen:** heeft het smoorventiel een pijl (eenrichtingsversie), laat die
  dan naar het vulventiel wijzen. Helemaal open staat de klep op volle doorstroming.

**Draadsoorten**

- G1/8 en G1/4 zijn BSP-draad (ook PT of BSPT op AliExpress). Die passen in elkaar,
  met PTFE-tape bij PT.
- **Geen NPT kopen:** NPT heeft een andere spoed (27 in plaats van 28 gangen per inch)
  en loopt vast of lekt in een G-poort. Let daar vooral op bij de druksensoren; die
  worden vaak met 1/8 NPT verkocht.
- M5 is overal M5×0,8.
- **Slang:** alles in 4 mm (4×2,5). Bij één bewegingsrichting staat maar één vulventiel
  open (ca. 40 Nl/min); daarvoor is 4 mm slang ruim genoeg.
- **Invoerheffing:** €3 + btw per productcategorie per zending. Daarom zo min mogelijk
  verschillende soorten: geen 6 mm slang en geen Y-stuk.

## Elektrisch

- **Pico 2 → ULN2803A:** 4 PWM-pinnen, één per ventiel. De ULN2803A schakelt de
  min-kant van elke spoel. Een VQ110-spoel trekt maar ongeveer 40–60 mA, ruim binnen
  wat de chip aankan (500 mA per kanaal). De vrijloopdiodes zitten in de chip: pin 10
  (COM) aan +24 V.
  - Een diode vertraagt het dichtgaan van het ventiel een beetje. Als dat in T1
    meetbaar is, voegen we per spoel een zenerdiode toe.
- **Spoelen:** rood aan +24 V, zwart aan een uitgang van de ULN2803A. Let op plus en
  min: het ingebouwde lampje en de beveiliging werken maar in één richting.
- **Noodstop en hoofdventiel:** de +24 V van de adapter gaat eerst door de noodstop.
  Daarachter hangen het hoofdventiel (rechtstreeks, dus altijd aan zolang de noodstop
  niet is ingedrukt) en de plus van de vier VQ110U-spoelen. Ingedrukt: alles valt af,
  ook als de software vastloopt.
- **Potmeter:** aan 3,3 V van de Pico, loper op ADC0 (GP26).
- **Druksensoren:** aan 5 V uit een LM7805C die op de 24 V zit, niet aan de USB-5 V.
  - De uitgang van deze sensoren schaalt mee met hun voedingsspanning. De USB-spanning
    schommelt tot ±5%, en dat zou direct ±5% meetfout geven.
  - De twee sensoren trekken samen ca. 20 mA; de 7805 verstookt dan (24 − 5) V × 0,02 A
    ≈ 0,4 W. Dat kan zonder koelplaatje. Een lineaire regelaar geeft een rustigere
    spanning dan een schakelende step-down, en dat is beter voor analoge metingen.
  - Condensatoren: 1 µF tussen IN en GND, 100 nF tussen OUT en GND, dicht bij de pootjes.
  - De 7805 zit vóór de noodstop, zodat de sensoren blijven meten als de noodstop is
    ingedrukt.
  - Elke sensoruitgang gaat via een spanningsdeler 10 kΩ (boven) / 15 kΩ (onder) naar
    ADC1 (GP27) en ADC2 (GP28). Zo wordt 5,0 V omgezet naar 3,0 V. Dat is veilig voor de
    Pico, of de sensor nu 0,5–4,5 V of 0–5 V geeft.
  - Welke uitgang het is, blijkt bij de eerste meting: op 0 bar geeft hij ongeveer 0,5 V
    of ongeveer 0 V. De software kalibreert op 0 bar en op een bekende druk (de
    manometer van de drukregelaar).
- **Ruis:** een condensator van 100 nF van elke ADC-ingang naar GND.
- **Massa:** de min van de 24 V-adapter, pin 9 (GND) van de ULN2803A en GND van de
  Pico aan elkaar.
- **De pc via USB:** levert stroom aan de Pico en ontvangt de meetgegevens
  (positie, twee drukken, ventielstanden). Dat gebeurt honderden keren per seconde.
- **Voeding:** een gesloten 24 V-stekkeradapter (minimaal 0,5 A, liever 1–2 A), geen
  losse netvoeding met schroefklemmen. Zo zit er geen 230 V aan de opstelling.
  Verbruik: 4 ventielspoelen max. ~250 mA, hoofdventiel ~125 mA, 7805 + sensoren
  ~25 mA; samen ~400 mA in het slechtste geval.

## Mechanisch

- **Eerst liggend:** cilinder en potmeter evenwijdig op een plank, stang en potmeter
  aan elkaar gekoppeld met een beugeltje.
- **Daarna staand:** de cilinder tilt een gewicht van 2–5 kg. Zo moet de regeling
  ook tegen de zwaartekracht in werken, net als straks in de arm.
  - Rekenvoorbeeld: Ø20 op 3 bar duwt 94 N, ongeveer 9,5 kg. Dat geeft genoeg
    reserve.

## Regeling in lagen

- **Snelle laag, op de Pico:** leest positie en drukken en stuurt de ventielen, 200–500
  keer per seconde. Deze laag houdt de cilinder op de gevraagde positie en stijfheid.
  - Vertragingen in deze lus: klep 2–3,5 ms, een drukgolf door 1 m slang ca. 3 ms,
    en het vullen van de kamer (tientallen ms).
  - Bij deze snelheden is alleen terugkoppeling nodig, geen feedforward.
- **Langzame laag, op de pc (programma of AI):** geeft ongeveer 10 keer per seconde
  een nieuwe doelpositie en stijfheid door.

Ter vergelijking: bij een mens komt een bewuste reactie na ongeveer 0,1–0,2 s, een
reflex via het ruggenmerg na enkele tientallen ms. Spieren geven daarbij van nature
mee. De stijfheidsregeling, met druk in beide kamers tegelijk, doet hetzelfde.

## Proeven en wanneer ze geslaagd zijn

Elke proef levert een logbestand op (CSV) en de getallen hieronder. Een proef is pas
geslaagd als het getal gemeten is, niet als het er goed uitziet. De grenswaarden zijn
een voorstel en worden na T1 bijgesteld als dat nodig is.

| Proef | Wat | Geslaagd als |
|---|---|---|
| T0 Lektest | Kamer vullen tot 3 bar, alle ventielen dicht, 60 s wachten | Drukval < 0,1 bar in 60 s |
| T1 Ventielen | Eén ventiel 10 ms aan; drukverloop in de kamer meten | Druk begint < 10 ms na het signaal te stijgen; PWM-frequentie gekozen |
| T2 Aan/uit-regeling | Naar 75 mm sturen met alleen vol open/dicht, met dode zone | Komt tot stilstand binnen ±3 mm |
| T3 PWM-regeling | Sprong van 20 → 80 mm en terug | Doorschot < 5 mm, stil binnen 1 s, restfout < ±1 mm |
| T4 Herhaalbaarheid | 10× van wisselende kanten naar 50 mm | Spreiding < ±1 mm |
| T5 Last | Staand, 2–5 kg, sprong 20 → 80 mm, dan vasthouden | Zelfde als T3; zakt < 1 mm in 60 s |
| T6 Stijfheid | Op 50 mm, stijfheid laag/hoog, met de hand of een gewicht duwen | Meetbaar verschil in uitwijking bij dezelfde kracht |
| T7 Belastingsgraad | Staand, 5 bar, gewicht stap voor stap verhogen (Ø20 kan statisch ca. 16 kg tillen) | Bij elke stap T3 herhalen. Uitkomst: het hoogste percentage van de statische kracht waarbij T3 nog slaagt. Dat getal bepaalt de cilindermaten van de arm. |

## Veiligheid

- **Druk:** begin op 2–3 bar en ga nooit boven de 6 bar (de grens van de ventielen
  is 7 bar).
- **Afsluitschuif:** binnen handbereik. Na het dichtschuiven is de toevoerleiding
  drukloos. De cilinderkamers niet: daar zit de lucht achter dichte ventielen.
- **Noodstop:** onderbreekt de 24 V naar alle ventielen. Alle vul- en leegventielen
  gaan dicht, dus de cilinder houdt zijn lucht vast en zakt niet weg. Het hoofdventiel
  sluit de toevoer af en ontlucht die. Blijft een vulventiel hangen, dan komt er toch
  geen lucht meer bij.
- **Bij elke opstart:** draag een veiligheidsbril, houd je handen weg van de stang en
  het beugeltje, en zet de slangen vast. Een losschietende slang zwiept.
- **Software:** zet bij een fout, bij het opstarten en als het USB-contact wegvalt
  alle ventielen uit. In uit-stand houdt de cilinder zijn lucht vast.
- **Cilinder drukloos maken:** eerst de afsluitschuif dicht, dan de leegventielen V2 en
  V4 openen, via de software of met de handbediening (drukknopje) op het ventiel zelf.
  Pas daarna aan de opstelling sleutelen.
- **Pneumatiek is niet ongevaarlijk:** Ø20 op 6 bar duwt bijna 19 kg, en de cilinders
  van de arm worden vele malen sterker. De veiligheid van de arm moet uit het ontwerp
  komen: begrensde druk, begrensde snelheid en meegeven. Het medium zelf maakt hem
  niet veilig.

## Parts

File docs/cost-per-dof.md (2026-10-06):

# Cost per DOF

A DOF (degree of freedom) here is one cylinder with its valves, sensors and controller.
Shared parts (compressor, regulator, power supply) are not included.

## Test rig (October 2026)

| Part | Price |
|---|---|
| 4× SMC VQ110U | €104 |
| Cylinder MAL20 | €10 |
| Linear potentiometer KTC-175 | €16–28 |
| 2× pressure sensor (stainless, G1/4) | €25–32 |
| Fittings, tube, silencers | ~€10 |
| Raspberry Pi Pico 2 | €7 |
| **Total** | **approx. €175–190** |

The valves are about 58% of the cost. The test rig keeps all sensors and four valves,
because it has to show what the arm really needs.

## Possible savings for the arm

Each saving depends on a measurement in the test rig:

| Saving | From → to | Decided by |
|---|---|---|
| AS5600 angle sensor on the joint instead of a linear potentiometer | €16–28 → ~€3 | Accuracy of the AS5600 on the joint |
| Bare pressure sensor chips (e.g. XGZP6847A, 0–1000 kPa, 0.5–4.5 V) instead of stainless transducers | €25–32 → ~€6–10 | Whether pressure feedback is needed (T3/T6 with and without) |

With both savings: about €150 per DOF, plus the larger cylinders for shoulder and elbow.

Four valves per cylinder remain necessary: the cylinder has to be able to hold its
position for safety. Cheap "VQ110" listings at €7–13 are bait prices for a different
item, not a real alternative.

## Cost per DOF versus joint torque (estimate)

A rough estimate per drive type, per DOF, without shared parts (compressor, hydraulic power
unit, power supply). Prices are indicative (October 2026) and still to be checked when a
choice depends on them.

| Joint torque | Electric (gearbox + motor) | Pneumatic | Hydraulic |
|---|---|---|---|
| Small (wrist, ~20 Nm) | **cheapest**: stepper with planetary gearbox, €50–100 | €150–190 | €450–600 + power unit |
| Medium (elbow, ~80 Nm) | €300–600 | €170–220 (Ø50) | €450–600 |
| Large (shoulder, 160–300 Nm) | €600–1200+ (harmonic size 32, servo, brake) | €180–250 (Ø63–80), but slow | €450–600 |
| Very large (1000+ Nm) | thousands of euros | impractically large cylinders | €500–700 |

Why it scales this way:
- **Electric:** the torque goes through gears and bearings, which have to become heavier
  and more precise, so the price rises steeply with torque.
- **Hydraulic:** more force mainly means a slightly larger cylinder, which is cheap; the
  valves and sensors stay almost the same. The power unit (€400–800) is a fixed cost
  shared by all DOFs. See [hydraulics.md](hydraulics.md).
- **Pneumatic:** the low pressure makes the cylinders large. The cost per DOF stays
  reasonable, but speed drops and air use rises.

Consequences:
- The hydraulic figure is mostly the four proportional cartridges (≈ €100 each); it
  hardly changes with force.
- At 15 kg pneumatics is the cheapest per DOF for the heavy joints; hydraulics costs more
  per DOF plus the power unit, and only pays back at large forces.
- For heavier work hydraulics wins.
- A mix is logical: cylinders for the heavy joints (shoulder, elbow), a small electric
  motor for the light ones (wrist rotation, gripper).

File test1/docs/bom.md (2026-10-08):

# Bill of materials — test 1

Generated from `docs/order-list.json` (repository root) by `build.py`. Prices in euro, * = estimate. Also as [CSV](bom.csv).

## 1. Valves (AliExpress)

Status: ordered (2026-10-04)

| # | Part | Variant | Price | Link |
|---|---|---|---|---|
| 1 | 5× fast 3/2 valve — Including shipping (store with 11 pages of reviews) | VQ110U-5M-M5 | €130.53 | [link](https://www.aliexpress.com/item/1005013133472109.html) |

## 2. Pneumatics, sensors and driver IC (AliExpress)

Status: ordered (2026-10-04)

| # | Part | Variant | Price | Link |
|---|---|---|---|---|
| 1 | Cylinder MAL20×150 | bore 20, stroke 150, standard (not CA), no magnet | €12.99 | [link](https://www.aliexpress.com/item/1005010583152545.html) |
| 1 | Linear potentiometer KTC | 175 mm, plain resistive 5 kΩ version (not 4–20 mA / LWF), type B (ball joint) | €28.19 | [link](https://www.aliexpress.com/item/1005006230077162.html) |
| 2 | Pressure sensor | #4 0–100 psi, output 0.5–4.5 V | €29.78 | [link](https://www.aliexpress.com/item/1005010385122677.html) |
| 1 | Filter + regulator AFR-2000 | G1/4, with gauge | €7.69 | [link](https://www.aliexpress.com/item/1005005324116810.html) |
| 1 | Shut-off slide valve HSV-08 | HSV-08 (G1/4), not HSV-06 | €4.09 | [link](https://www.aliexpress.com/item/1005010563686803.html) |
| 1 | Main valve 3V210-08 | NC, DC24V | €8.19 | [link](https://www.aliexpress.com/item/1005007341961878.html) |
| 1 | Emergency stop, mounted in a box | plastic box with yellow STOP label, no lid or guard; NC contact (or 1NO+1NC) | €8.29* | [link](https://www.aliexpress.com/item/1005005858101621.html) |
| 8 | Straight push-in fitting, per piece (4000+ sold) — 6 for the valves, 2 spare | 4 mm – M5 (PC4-M5) | €3.92 | [link](https://www.aliexpress.com/item/1005002796005278.html) |
| 3 | Straight push-in fitting, per piece — 2 needed, 1 spare | 4 mm – 1/8 (PC4-01) | €1.83 | [link](https://www.aliexpress.com/item/1005002796005278.html) |
| 5 | Straight push-in fitting, per piece — Regulator, slide valve, main valve (3–5 needed) | 4 mm – 1/4 (PC4-02) | €3.45 | [link](https://www.aliexpress.com/item/1005002796005278.html) |
| 1 | M5 blanking plug (10 pieces) | M5 | €3.05 | [link](https://www.aliexpress.com/item/1005004886533500.html) |
| 1 | Tee 4 mm | PE4, 10 pieces | €2.80 | [link](https://www.aliexpress.com/item/1005006534920138.html) |
| 1 | Push-in fitting, female 1/4" → 4 mm (bag of 10, for the pressure sensors) — Rc 1/4 (tapered); seal the G1/4 sensor with PTFE tape | PCF4-02 | €6.49 | [link](https://www.aliexpress.com/item/32830226405.html) |
| 2 | PU tube 5 m — Everything in 4 mm tube; 6 mm is not needed | 4×2.5 mm, 5 m (clear) | €4.84 | [link](https://www.aliexpress.com/item/1005007992615899.html) |
| 2 | Foot mount (LB) for MAL20 — Not needed for test 1 (the cylinder pivots); spare for a fixed set-up | LB, 20 mm | €8.98 | [link](https://www.aliexpress.com/item/1005007235783406.html) |
| 1 | Nut M22×1.5 — For the rear cover; the cylinder usually comes with one nut only | M22×1.5 (MAL20/25) | €3.11 | [link](https://www.aliexpress.com/item/1005007235783406.html) |
| 1 | ULN2803A Darlington array (DIP-18), 10 pieces — Only the ULN2803 in this listing, no mix-up with 2802/2804 (the 2804 does not switch on 3.3 V) | ULN2803APG DIP-18 | €2.23 | [link](https://www.aliexpress.com/item/1005006852404177.html) |
| 1 | Inline flow restrictor 4 mm (2 pieces) — Used after T7 to mimic a smaller valve | 4 mm | €3.36 | [link](https://www.aliexpress.com/item/1005008810108635.html) |
| 1 | Rod clevis (Y) for MAL20 — Connects the cylinder rod to the arm (test 1) | Y/MA MAL20 | €3.85 | [link](https://www.aliexpress.com/item/1005007235783406.html) |
| 1 | M5 exhaust silencer (5 pieces) | Short M5/5PCS | €1.64 | [link](https://www.aliexpress.com/item/1005004014973967.html) |

## 3. Electronics (Tinytronics, NL)

Status: received (2026-10-07)

| # | Part | Variant | Price | Link |
|---|---|---|---|---|
| 1 | Raspberry Pi Pico 2W (RP2350, Wi-Fi) — headers soldered on yourself | SKU 006795 | €9.25 | [link](https://www.tinytronics.nl/) |
| 4 | 40-pin male header strip (2× 20 pins needed for the Pico) | SKU 000160 | €1.60 |  |
| 2 | LM7805C 5 V voltage regulator (TO-220) — 1 spare | SKU 000236 | €1.00 |  |
| 2 | Ceramic capacitor 1 µF, 50 V — 7805 input (1 + 1 spare) | SKU 007096 | €0.40 |  |
| 6 | Ceramic capacitor 100 nF, 50 V — 7805 output + 3 ADC inputs + 2 spare | SKU 000226 | €0.60 |  |
| 1 | DC jack female 5.5 mm (5.5/2.1) to screw terminal — Check that the 24 V adapter plug is 5.5/2.1 | SKU 000287 | €1.00 |  |
| 1 | Breadboard 830 points (EIC premium) | SKU 006327 | €5.00 |  |
| 1 | Resistor 10 kΩ 1/4 W, 10 pieces — Top of the pressure sensor dividers (2 needed) | SKU 007625 | €0.50 |  |
| 3 | Resistor 47 kΩ 1/4 W, 10 pieces — 3 in parallel = 15.7 kΩ, bottom of each divider (6 needed) | SKU 007626 | €1.50 |  |
| 1 | Micro-USB cable (data), 1 m | Goobay 72227 | €2.75 |  |
| 2 | Stranded wire 0.5 mm², black, 1 m — 24 V, e-stop, valves (screw terminals) | SKU 003430 | €2.00 |  |
| 2 | Stranded wire 0.5 mm², red, 1 m | SKU 003427 | €2.00 |  |
| 3 | DuPont jumper wires male-male 10 cm, 100 pieces (blue, black, red) — Breadboard wiring: red = plus, black = ground, blue = signal | SKU 002978/002980/002977 | €13.50 |  |

## 4. DIY store

Status: still to buy

| # | Part | Variant | Price | Link |
|---|---|---|---|---|
| 1 | Plywood 18 mm: base plate 400×300, 2 cheeks 450×120, 2 blocks 60×60 (spacer block) | DIY stores often cut to size | €15.00* |  |
| 1 | Aluminium flat bar 40×5 mm (or 40×4), 50 cm — the arm |  | €8.00* |  |
| 1 | Aluminium strip 20×3 mm (or 20×2), 30 cm — potentiometer bracket + mounting strip |  | €3.00* |  |
| 1 | Aluminium tube 10×1 mm (8 mm inside), 50 cm — spacer sleeves |  | €4.00* |  |
| 2 | Ball bearing 608-2RS (8×22×7) — arm hinge | skateboard bearing | €3.00* |  |
| 2 | Bolt M8×80 + 2 washers + M8 lock nut — hinge and rear pivot |  | €2.00* |  |
| 2 | Nut M8 (standard M8 = M8×1.25) — potentiometer bracket on the rod |  | €0.40* |  |
| 2 | Bolt M5×16 + nut — potentiometer rod to the bracket |  | €0.40* |  |
| 2 | Hose clamp 20–32 mm — potentiometer on the cylinder |  | €1.60* |  |
| 4 | Angle bracket 40×40 + wood screws 4×30 / 4×40 | cheeks and block onto the base plate | €3.20* |  |
| 2 | F-clamp — clamp the rig to the table edge |  | €12.00* |  |
| 1 | Load: M8×60 bolt, 2 large washers M8×40, nut — for 1 kg dumbbell plates (own, up to 5 for T7) — Plates bolted to the arm end: they cannot swing |  | €1.50* |  |
| 1 | Plug nipple G1/4 male, matching the compressor coupler | buy after the compressor arrives | €3.00* |  |
| 1 | Tube cutter |  | €5.00* |  |
| 1 | PTFE tape |  | €1.50* |  |
| 1 | Multimeter (if you do not have one) — Needed for the incoming inspection, coil checks and calibration |  | €20.00* |  |

## 5. Compressor (bol.com)

Status: received (2026-10-06)

| # | Part | Variant | Price | Link |
|---|---|---|---|---|
| 1 | Stanley silent compressor DST 100/8/6 — Quiet enough for indoor testing. For the full arm a 6 l tank may be small; add a buffer tank later. Check the coupler type before buying the plug nipple. | 6 l, 8 bar, 105 l/min (intake), 59 dB, oil-free, 750 W | €160.00* | [link](https://www.bol.com/nl/nl/p/stanley-silent-compressor-dst-100-8-6-olievrij/9200000106192675/) |

**Total approx. €564** (excluding shipping and import duty).

## Tools

- Jigsaw or hand saw (wood)
- Hacksaw and file (aluminium)
- Drill with wood bits 5 and 8.5 mm, metal bits 5.5 and 8.5 mm, 22 mm Forstner bit
- Screwdrivers, spanners 8, 10, 13 mm, hex keys
- Wire stripper, small screwdriver for screw terminals
- Soldering iron (only if the Pico comes without header pins)
- Safety glasses
- Tape measure, try square, awl or centre punch

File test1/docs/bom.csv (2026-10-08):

order | part | variant | qty | price | estimate | link | note | status
1. Valves (AliExpress) | 5× fast 3/2 valve | VQ110U-5M-M5 | 1 | 130.53 | False | https://www.aliexpress.com/item/1005013133472109.html | Including shipping (store with 11 pages of reviews) | ordered (2026-10-04)
2. Pneumatics, sensors and driver IC (AliExpress) | Cylinder MAL20×150 | bore 20, stroke 150, standard (not CA), no magnet | 1 | 12.99 | False | https://www.aliexpress.com/item/1005010583152545.html |  | ordered (2026-10-04)
2. Pneumatics, sensors and driver IC (AliExpress) | Linear potentiometer KTC | 175 mm, plain resistive 5 kΩ version (not 4–20 mA / LWF), type B (ball joint) | 1 | 28.19 | False | https://www.aliexpress.com/item/1005006230077162.html |  | ordered (2026-10-04)
2. Pneumatics, sensors and driver IC (AliExpress) | Pressure sensor | #4 0–100 psi, output 0.5–4.5 V | 2 | 14.89 | False | https://www.aliexpress.com/item/1005010385122677.html |  | ordered (2026-10-04)
2. Pneumatics, sensors and driver IC (AliExpress) | Filter + regulator AFR-2000 | G1/4, with gauge | 1 | 7.69 | False | https://www.aliexpress.com/item/1005005324116810.html |  | ordered (2026-10-04)
2. Pneumatics, sensors and driver IC (AliExpress) | Shut-off slide valve HSV-08 | HSV-08 (G1/4), not HSV-06 | 1 | 4.09 | False | https://www.aliexpress.com/item/1005010563686803.html |  | ordered (2026-10-04)
2. Pneumatics, sensors and driver IC (AliExpress) | Main valve 3V210-08 | NC, DC24V | 1 | 8.19 | False | https://www.aliexpress.com/item/1005007341961878.html |  | ordered (2026-10-04)
2. Pneumatics, sensors and driver IC (AliExpress) | Emergency stop, mounted in a box | plastic box with yellow STOP label, no lid or guard; NC contact (or 1NO+1NC) | 1 | 8.29 | True | https://www.aliexpress.com/item/1005005858101621.html |  | ordered (2026-10-04)
2. Pneumatics, sensors and driver IC (AliExpress) | Straight push-in fitting, per piece (4000+ sold) | 4 mm – M5 (PC4-M5) | 8 | 0.49 | False | https://www.aliexpress.com/item/1005002796005278.html | 6 for the valves, 2 spare | ordered (2026-10-04)
2. Pneumatics, sensors and driver IC (AliExpress) | Straight push-in fitting, per piece | 4 mm – 1/8 (PC4-01) | 3 | 0.61 | False | https://www.aliexpress.com/item/1005002796005278.html | 2 needed, 1 spare | ordered (2026-10-04)
2. Pneumatics, sensors and driver IC (AliExpress) | Straight push-in fitting, per piece | 4 mm – 1/4 (PC4-02) | 5 | 0.69 | False | https://www.aliexpress.com/item/1005002796005278.html | Regulator, slide valve, main valve (3–5 needed) | ordered (2026-10-04)
2. Pneumatics, sensors and driver IC (AliExpress) | M5 blanking plug (10 pieces) | M5 | 1 | 3.05 | False | https://www.aliexpress.com/item/1005004886533500.html |  | ordered (2026-10-04)
2. Pneumatics, sensors and driver IC (AliExpress) | Tee 4 mm | PE4, 10 pieces | 1 | 2.8 | False | https://www.aliexpress.com/item/1005006534920138.html |  | ordered (2026-10-04)
2. Pneumatics, sensors and driver IC (AliExpress) | Push-in fitting, female 1/4" → 4 mm (bag of 10, for the pressure sensors) | PCF4-02 | 1 | 6.49 | False | https://www.aliexpress.com/item/32830226405.html | Rc 1/4 (tapered); seal the G1/4 sensor with PTFE tape | ordered (2026-10-04)
2. Pneumatics, sensors and driver IC (AliExpress) | PU tube 5 m | 4×2.5 mm, 5 m (clear) | 2 | 2.42 | False | https://www.aliexpress.com/item/1005007992615899.html | Everything in 4 mm tube; 6 mm is not needed | ordered (2026-10-04)
2. Pneumatics, sensors and driver IC (AliExpress) | Foot mount (LB) for MAL20 | LB, 20 mm | 2 | 4.49 | False | https://www.aliexpress.com/item/1005007235783406.html | Not needed for test 1 (the cylinder pivots); spare for a fixed set-up | ordered (2026-10-04)
2. Pneumatics, sensors and driver IC (AliExpress) | Nut M22×1.5 | M22×1.5 (MAL20/25) | 1 | 3.11 | False | https://www.aliexpress.com/item/1005007235783406.html | For the rear cover; the cylinder usually comes with one nut only | ordered (2026-10-04)
2. Pneumatics, sensors and driver IC (AliExpress) | ULN2803A Darlington array (DIP-18), 10 pieces | ULN2803APG DIP-18 | 1 | 2.23 | False | https://www.aliexpress.com/item/1005006852404177.html | Only the ULN2803 in this listing, no mix-up with 2802/2804 (the 2804 does not switch on 3.3 V) | ordered (2026-10-04)
2. Pneumatics, sensors and driver IC (AliExpress) | Inline flow restrictor 4 mm (2 pieces) | 4 mm | 1 | 3.36 | False | https://www.aliexpress.com/item/1005008810108635.html | Used after T7 to mimic a smaller valve | ordered (2026-10-04)
2. Pneumatics, sensors and driver IC (AliExpress) | Rod clevis (Y) for MAL20 | Y/MA MAL20 | 1 | 3.85 | False | https://www.aliexpress.com/item/1005007235783406.html | Connects the cylinder rod to the arm (test 1) | ordered (2026-10-04)
2. Pneumatics, sensors and driver IC (AliExpress) | M5 exhaust silencer (5 pieces) | Short M5/5PCS | 1 | 1.64 | False | https://www.aliexpress.com/item/1005004014973967.html |  | ordered (2026-10-04)
3. Electronics (Tinytronics, NL) | Raspberry Pi Pico 2W (RP2350, Wi-Fi) — headers soldered on yourself | SKU 006795 | 1 | 9.25 | False | https://www.tinytronics.nl/ |  | received (2026-10-07)
3. Electronics (Tinytronics, NL) | 40-pin male header strip (2× 20 pins needed for the Pico) | SKU 000160 | 4 | 0.4 | False |  |  | received (2026-10-07)
3. Electronics (Tinytronics, NL) | LM7805C 5 V voltage regulator (TO-220) | SKU 000236 | 2 | 0.5 | False |  | 1 spare | received (2026-10-07)
3. Electronics (Tinytronics, NL) | Ceramic capacitor 1 µF, 50 V | SKU 007096 | 2 | 0.2 | False |  | 7805 input (1 + 1 spare) | received (2026-10-07)
3. Electronics (Tinytronics, NL) | Ceramic capacitor 100 nF, 50 V | SKU 000226 | 6 | 0.1 | False |  | 7805 output + 3 ADC inputs + 2 spare | received (2026-10-07)
3. Electronics (Tinytronics, NL) | DC jack female 5.5 mm (5.5/2.1) to screw terminal | SKU 000287 | 1 | 1.0 | False |  | Check that the 24 V adapter plug is 5.5/2.1 | received (2026-10-07)
3. Electronics (Tinytronics, NL) | Breadboard 830 points (EIC premium) | SKU 006327 | 1 | 5.0 | False |  |  | received (2026-10-07)
3. Electronics (Tinytronics, NL) | Resistor 10 kΩ 1/4 W, 10 pieces | SKU 007625 | 1 | 0.5 | False |  | Top of the pressure sensor dividers (2 needed) | received (2026-10-07)
3. Electronics (Tinytronics, NL) | Resistor 47 kΩ 1/4 W, 10 pieces | SKU 007626 | 3 | 0.5 | False |  | 3 in parallel = 15.7 kΩ, bottom of each divider (6 needed) | received (2026-10-07)
3. Electronics (Tinytronics, NL) | Micro-USB cable (data), 1 m | Goobay 72227 | 1 | 2.75 | False |  |  | received (2026-10-07)
3. Electronics (Tinytronics, NL) | Stranded wire 0.5 mm², black, 1 m | SKU 003430 | 2 | 1.0 | False |  | 24 V, e-stop, valves (screw terminals) | received (2026-10-07)
3. Electronics (Tinytronics, NL) | Stranded wire 0.5 mm², red, 1 m | SKU 003427 | 2 | 1.0 | False |  |  | received (2026-10-07)
3. Electronics (Tinytronics, NL) | DuPont jumper wires male-male 10 cm, 100 pieces (blue, black, red) | SKU 002978/002980/002977 | 3 | 4.5 | False |  | Breadboard wiring: red = plus, black = ground, blue = signal | received (2026-10-07)
4. DIY store | Plywood 18 mm: base plate 400×300, 2 cheeks 450×120, 2 blocks 60×60 (spacer block) | DIY stores often cut to size | 1 | 15.0 | True |  |  | still to buy
4. DIY store | Aluminium flat bar 40×5 mm (or 40×4), 50 cm — the arm |  | 1 | 8.0 | True |  |  | still to buy
4. DIY store | Aluminium strip 20×3 mm (or 20×2), 30 cm — potentiometer bracket + mounting strip |  | 1 | 3.0 | True |  |  | still to buy
4. DIY store | Aluminium tube 10×1 mm (8 mm inside), 50 cm — spacer sleeves |  | 1 | 4.0 | True |  |  | still to buy
4. DIY store | Ball bearing 608-2RS (8×22×7) — arm hinge | skateboard bearing | 2 | 1.5 | True |  |  | still to buy
4. DIY store | Bolt M8×80 + 2 washers + M8 lock nut — hinge and rear pivot |  | 2 | 1.0 | True |  |  | still to buy
4. DIY store | Nut M8 (standard M8 = M8×1.25) — potentiometer bracket on the rod |  | 2 | 0.2 | True |  |  | still to buy
4. DIY store | Bolt M5×16 + nut — potentiometer rod to the bracket |  | 2 | 0.2 | True |  |  | still to buy
4. DIY store | Hose clamp 20–32 mm — potentiometer on the cylinder |  | 2 | 0.8 | True |  |  | still to buy
4. DIY store | Angle bracket 40×40 + wood screws 4×30 / 4×40 | cheeks and block onto the base plate | 4 | 0.8 | True |  |  | still to buy
4. DIY store | F-clamp — clamp the rig to the table edge |  | 2 | 6.0 | True |  |  | still to buy
4. DIY store | Load: M8×60 bolt, 2 large washers M8×40, nut — for 1 kg dumbbell plates (own, up to 5 for T7) |  | 1 | 1.5 | True |  | Plates bolted to the arm end: they cannot swing | still to buy
4. DIY store | Plug nipple G1/4 male, matching the compressor coupler | buy after the compressor arrives | 1 | 3.0 | True |  |  | still to buy
4. DIY store | Tube cutter |  | 1 | 5.0 | True |  |  | still to buy
4. DIY store | PTFE tape |  | 1 | 1.5 | True |  |  | still to buy
4. DIY store | Multimeter (if you do not have one) |  | 1 | 20.0 | True |  | Needed for the incoming inspection, coil checks and calibration | still to buy
5. Compressor (bol.com) | Stanley silent compressor DST 100/8/6 | 6 l, 8 bar, 105 l/min (intake), 59 dB, oil-free, 750 W | 1 | 160.0 | True | https://www.bol.com/nl/nl/p/stanley-silent-compressor-dst-100-8-6-olievrij/9200000106192675/ | Quiet enough for indoor testing. For the full arm a 6 l tank may be small; add a buffer tank later. Check the coupler type before buying the plug nipple. | received (2026-10-06)

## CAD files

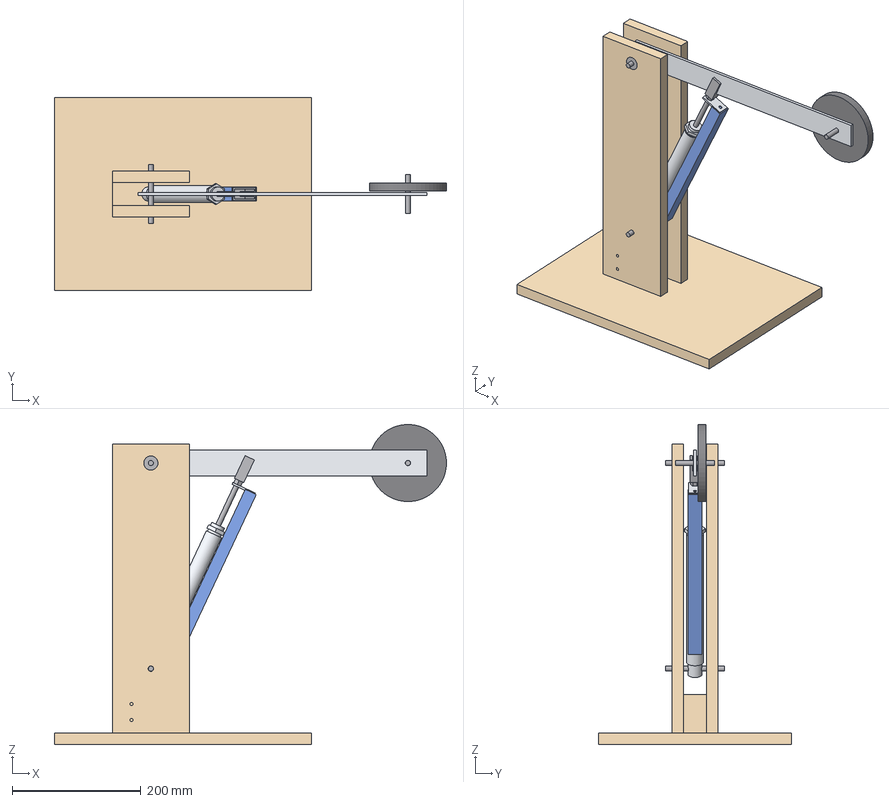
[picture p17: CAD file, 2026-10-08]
test1/out/cad/test1_assembly.step
610.0 x 300.0 x 498.0 mm
base_plate
cheek_left
cheek_right
spacer_block
arm
rod_clevis
potentiometer
pot_rod
pot_bracket
bearing_left
bearing_right
bolt_hinge
bolt_cylinder
load_plate_1
bolt_load

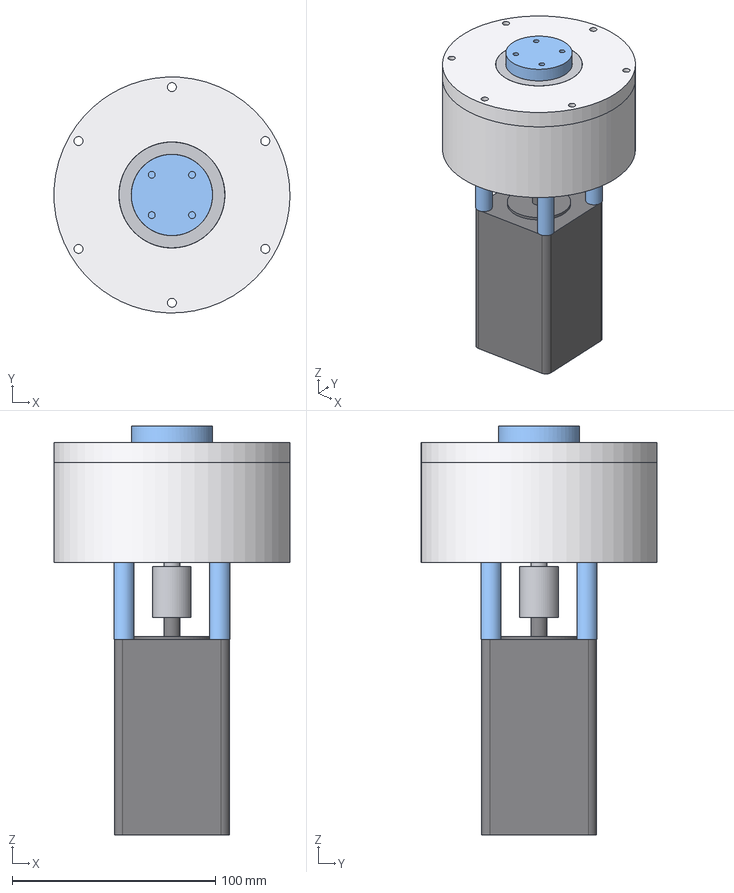
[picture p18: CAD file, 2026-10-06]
test1-cycloid/out/step/assembly.step
115.9 x 115.9 x 201.0 mm
housing
cover
motor
bearing_6808_rear
bearing_6808_front
standoff_0
standoff_1
standoff_2
standoff_3
housing_pin_0
housing_pin_1
housing_pin_2
housing_pin_3
housing_pin_4
housing_pin_5
housing_pin_6
housing_pin_7
housing_pin_8
housing_pin_9
housing_pin_10
housing_pin_11
housing_pin_12
housing_pin_13
housing_pin_14
housing_pin_15
housing_pin_16
housing_pin_17
housing_pin_18
housing_pin_19
housing_pin_20
housing_pin_21
housing_pin_22
housing_pin_23
housing_pin_24
shaft
coupling
cam
carrier_rear
carrier_front
bearing_608_rear
bearing_608_front
output_pin_0
output_pin_1
output_pin_2
output_pin_3
output_pin_4
output_pin_5
disc_0
bearing_6804_0
disc_1
bearing_6804_1

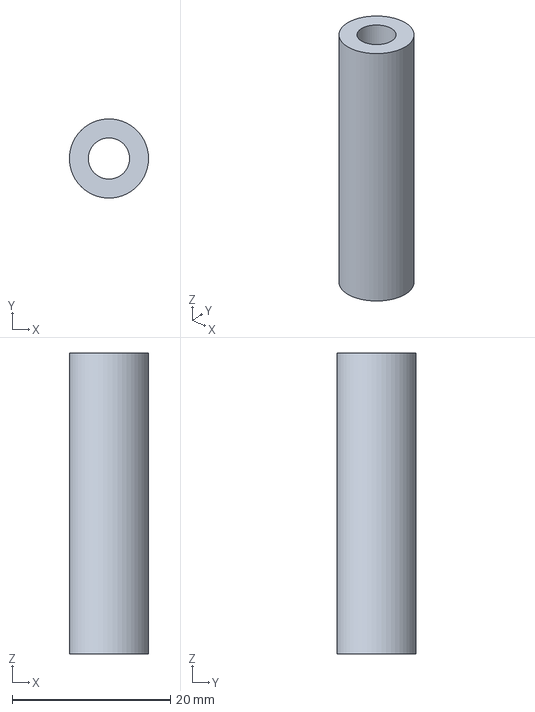
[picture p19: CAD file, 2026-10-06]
test1-cycloid/out/step/standoff.step
9.99 x 10.00 x 38.0 mm

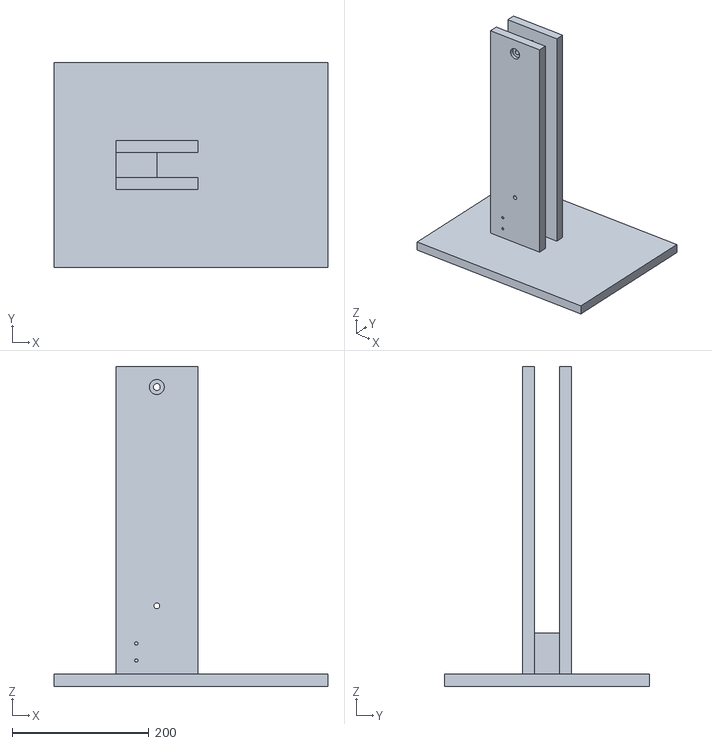
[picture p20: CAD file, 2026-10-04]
test1/out/meshes/upright.stl
400.0 x 300.0 x 468.0

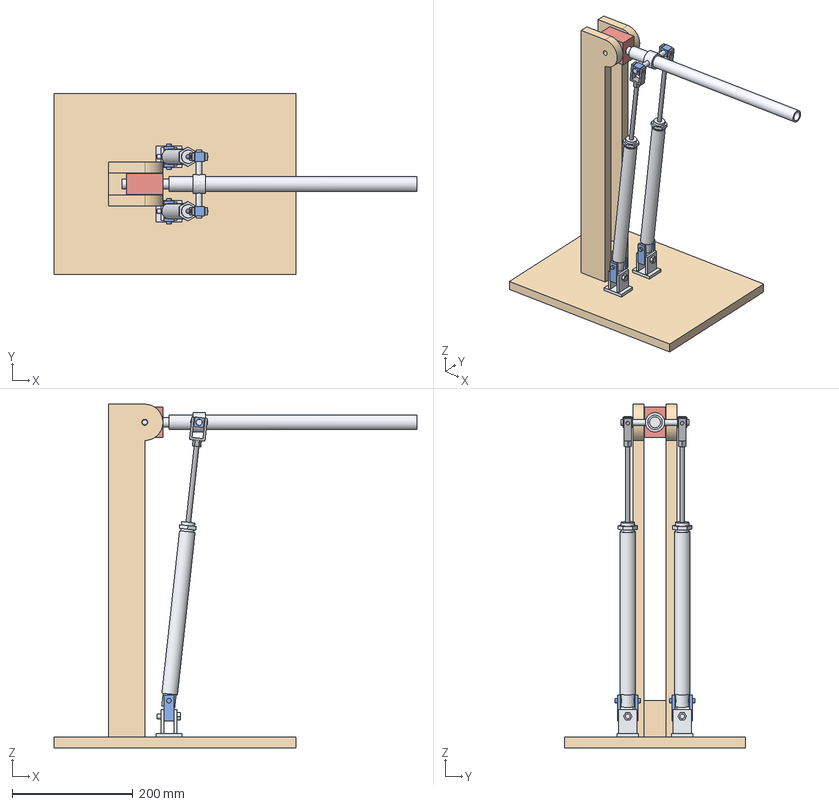
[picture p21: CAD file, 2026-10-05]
test2/out/cross_block/test2_concept.step
600.0 x 300.0 x 568.0 mm
base_plate
cheek_left
cheek_right
spacer_block
yoke
arm
cross_block_0
rod_0
lower_stand_0
lower_fork_0
cross_block_1
rod_1
lower_stand_1
lower_fork_1

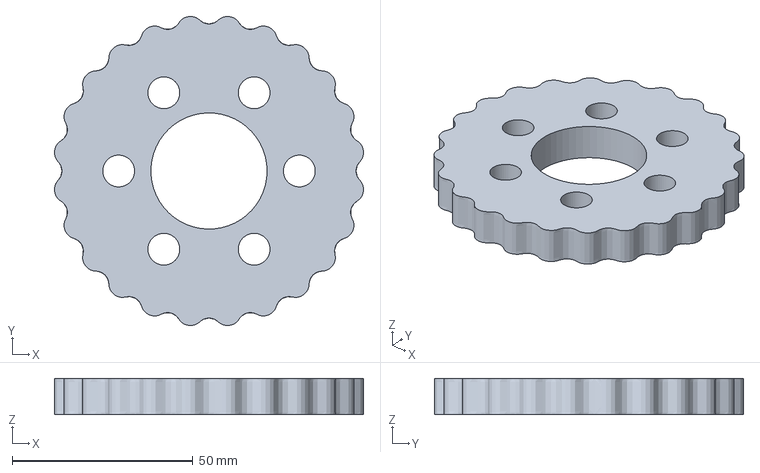
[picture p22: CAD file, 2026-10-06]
test1-cycloid/out/step/disc_0.step
85.5 x 85.5 x 10.0 mm

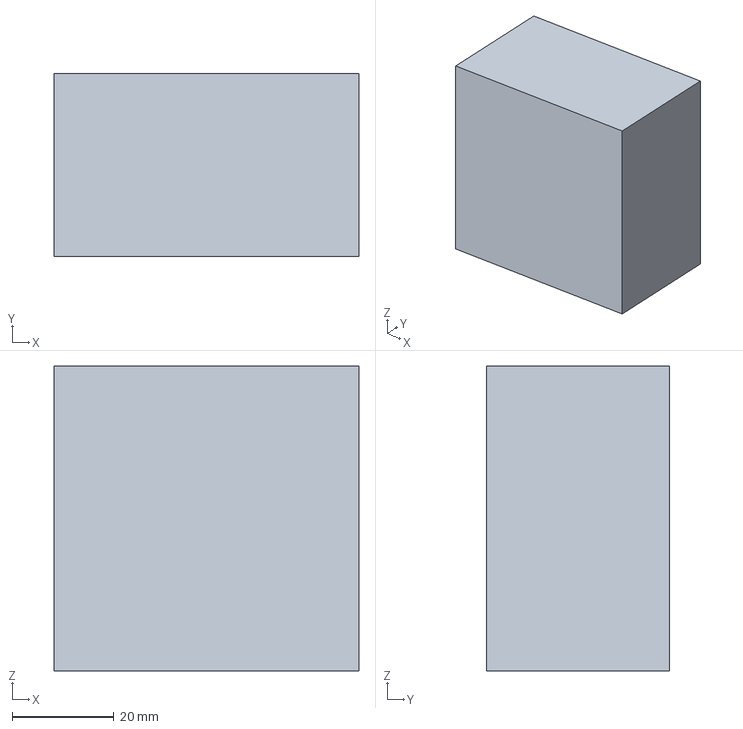
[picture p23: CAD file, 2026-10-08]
test1/out/cad/spacer_block.step
60.0 x 36.0 x 60.0 mm

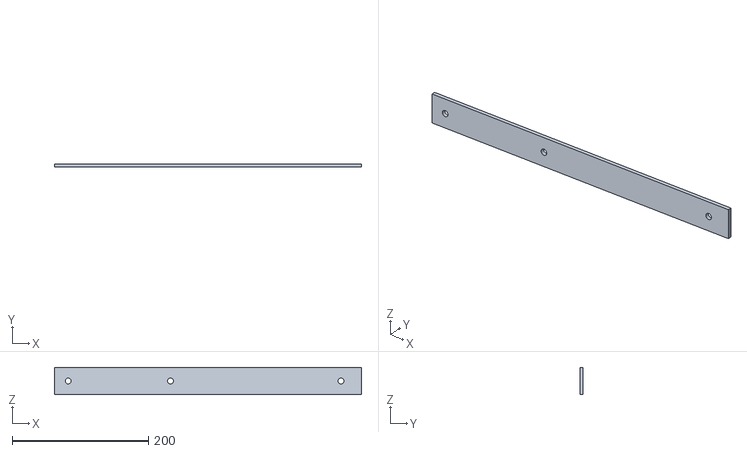
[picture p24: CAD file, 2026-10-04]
test1/out/meshes/arm.stl
450.0 x 5.00 x 40.0

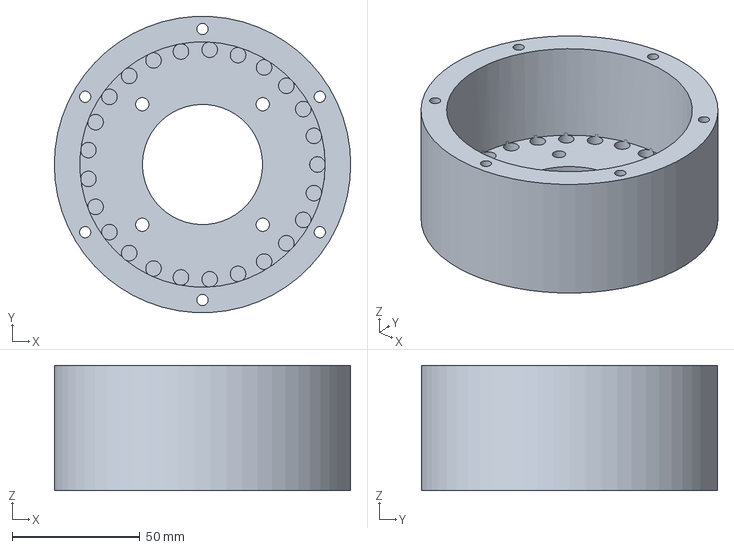
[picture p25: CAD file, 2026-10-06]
test1-cycloid/out/step/housing.step
116.0 x 115.8 x 49.0 mm

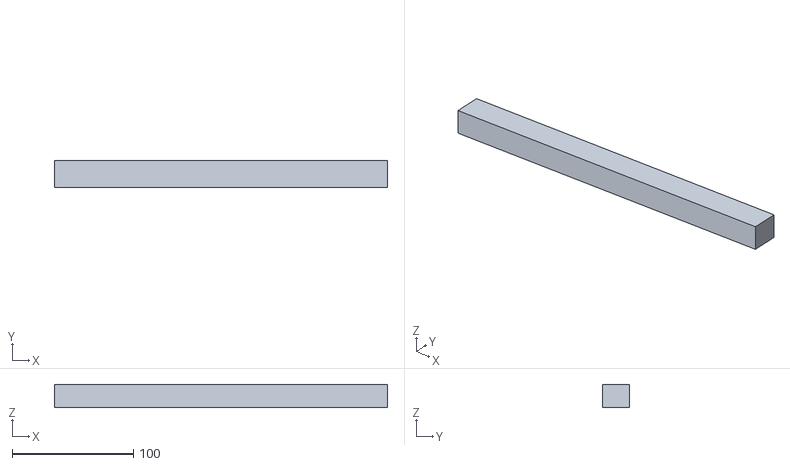
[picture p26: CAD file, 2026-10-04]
test1/out/meshes/potentiometer.stl
275.0 x 22.0 x 19.0

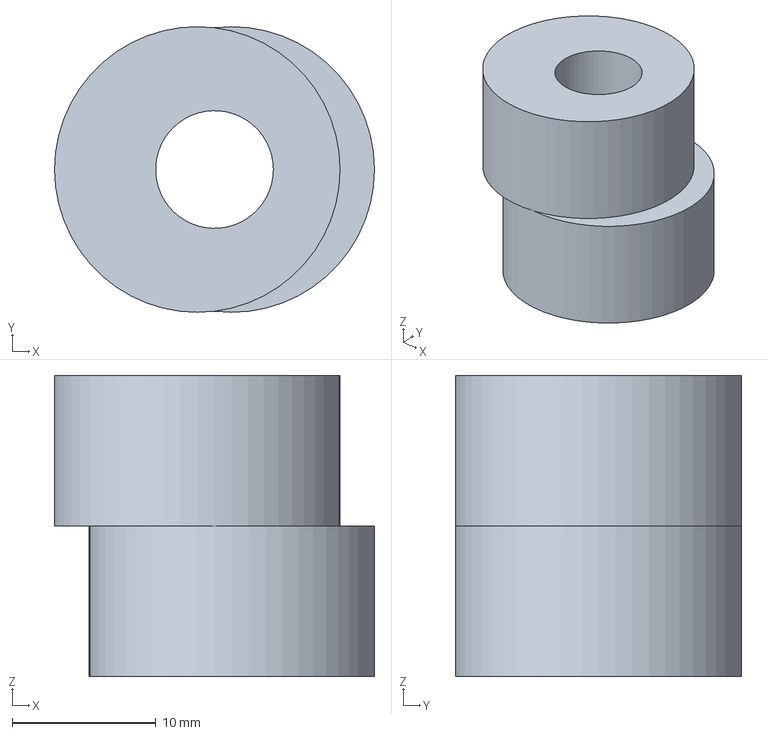
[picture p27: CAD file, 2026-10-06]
test1-cycloid/out/step/cam.step
22.3 x 19.9 x 21.0 mm

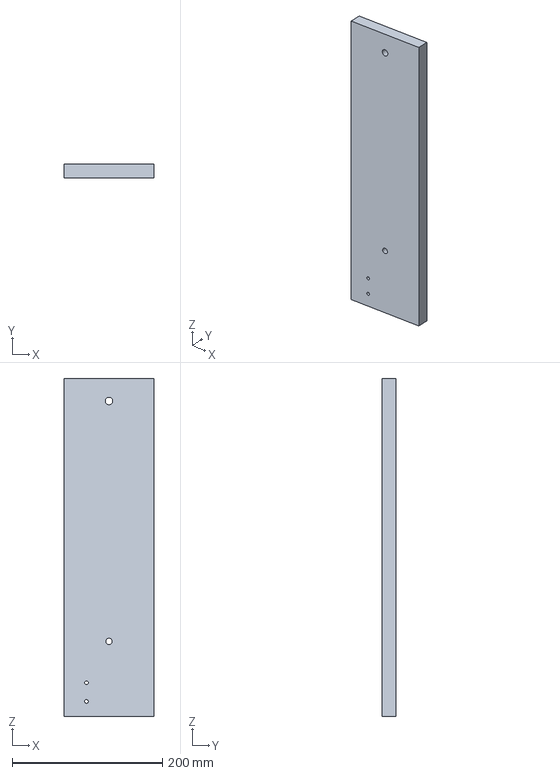
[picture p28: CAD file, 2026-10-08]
test1/out/cad/cheek.step
120.0 x 18.0 x 450.0 mm

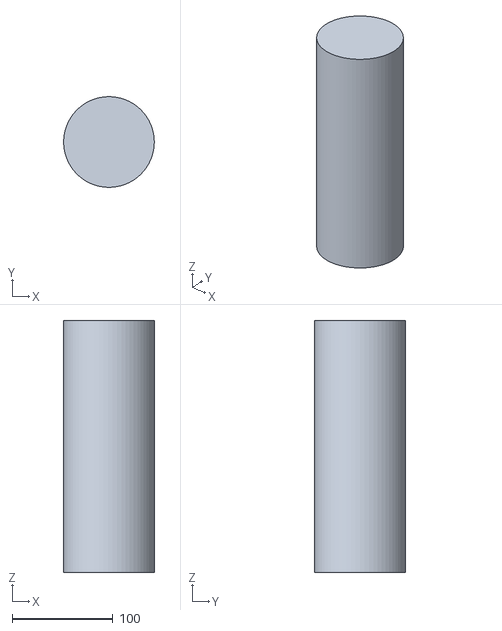
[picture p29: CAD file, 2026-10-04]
test1/out/meshes/bottle.stl
89.9 x 90.0 x 250.0

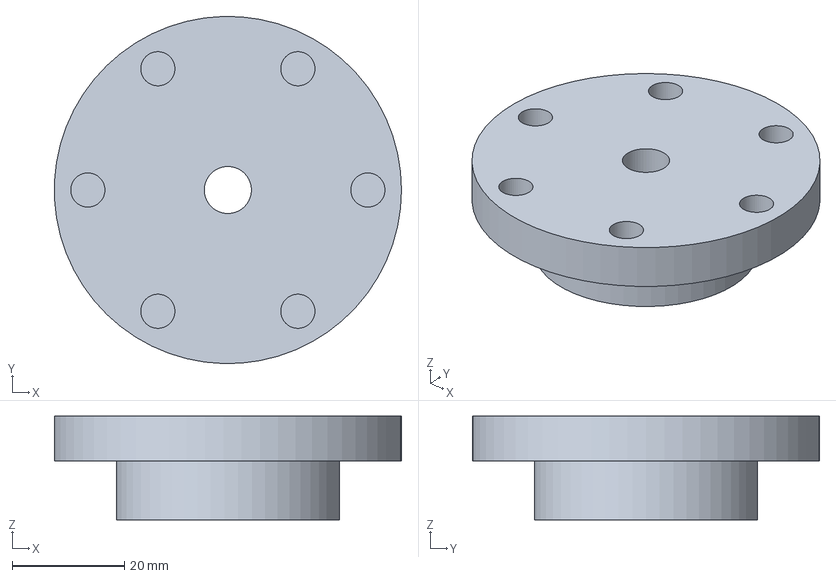
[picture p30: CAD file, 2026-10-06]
test1-cycloid/out/step/carrier_rear.step
62.0 x 62.0 x 18.5 mm

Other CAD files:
test1/out/cad/arm.step
test1/out/cad/pot_bracket.step
test1/out/meshes/rod.stl
test1-cycloid/out/step/fit_test.step
test1-cycloid/out/step/carrier_front.step
test1-cycloid/out/step/cover.step
test1-cycloid/out/step/disc_1.step
test1-cycloid/out/stl/cam.stl
test1-cycloid/out/stl/carrier_front.stl
test1-cycloid/out/stl/carrier_rear.stl
test1-cycloid/out/stl/cover.stl
test1-cycloid/out/stl/disc_0.stl
test1-cycloid/out/stl/disc_1.stl
test1-cycloid/out/stl/fit_test.stl
test1-cycloid/out/stl/housing.stl
test1-cycloid/out/stl/standoff.stl
test1/out/cad/arm.stl
test1/out/cad/arm_profile.dxf
test1/out/cad/base_plate.step
test1/out/cad/base_plate.stl
test1/out/cad/base_plate_profile.dxf
test1/out/cad/cheek.stl
test1/out/cad/cheek_profile.dxf
test1/out/cad/pot_bracket.stl
test1/out/cad/spacer_block.stl
test1/out/meshes/cylinder.stl
test2/out/test2_concept.step

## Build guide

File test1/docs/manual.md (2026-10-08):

# Manual for test 1 — arm with one degree of freedom

This manual takes you step by step through checking the parts, building, wiring,
installing the software, calibrating and running tests T0–T7.

At 📷 take a photo before you continue. It lets someone check your work before air or
power goes on; post it in an issue if you want feedback.

All dimensions come from `params.py` and are also in the drawings in `out/drawings/`.

---

## 0. Safety — read this first

- **Safety glasses on** as soon as there is compressed air on the rig. A tube that comes
  loose whips around and can hit your eye.
- **Start at 2–3 bar.** Only go to 5 bar after T0 to T2 went well. Never above 6 bar: the
  valves are rated for 7 bar, the pressure sensors for 6.9 bar.
- **Hands out from between the arm and the upright.** At 5 bar the cylinder pushes 157 N,
  which at the hinge is enough to crush fingers.
- **Emergency stop within reach.** Pressed: the 24 V drops out, all valves close and the
  main valve vents the supply line. The cylinder keeps its air; the arm stays where it is
  and does not fall.
- **Depressurise before working on the rig:**
  1. close the shut-off slide (supply depressurised);
  2. in the software `valve 0 1 0 1` (vent both chambers), or press the manual override
     button on vent valves V2 and V4;
  3. the regulator gauge and the pressure sensor readings must show 0 bar.
- **Clamp the rig down.** The arm reaches past the table edge. Clamp the base plate with
  two F-clamps, or the whole thing can tip over in a fast move.
- **No mains voltage on the rig.** Only the closed 24 V plug-in adapter.

---

## 1. Incoming inspection

Do this per parcel, **before** you confirm receipt on AliExpress. If something is wrong,
open a dispute with photos.

| Part | Check | Good if |
|---|---|---|
| 5× VQ110U-5M-M5 | label | says VQ110U-5M-M5, with sub-plate (white block with ports) |
| | coil resistance (multimeter Ω, red and black wire) | all five about equal: approx. 380–600 Ω (1–1.5 W at 24 V) |
| | 24 V on it briefly (red +, black −) | a clear click, the LED in the plug lights up |
| | blow into P (bicycle pump or mouth), coil off/on | off: closed, on: air comes out of A |
| Cylinder MAL20×150 | push the rod in and out by hand | moves evenly, without sticking |
| | ports | 1/8 thread; a PC4-01 screws in smoothly by hand for a few turns |
| | dimensions (measure!) | note the retracted pin-to-pin length — see step 5 |
| KTC-175 potentiometer | resistance between the pins | two pins give a fixed ~5 kΩ (the ends); the third is the wiper |
| | move the wiper | resistance wiper–end changes evenly with the rod |
| 2× pressure sensor | 5 V on it (red +, black −), measure the signal | 0 bar: approx. 0.5 V (or approx. 0 V for a 0–5 V type) |
| | thread | male G1/4 (fits the PCF4-02) |
| ULN2803A | — | tested in step 8 |
| Pico 2 W | hold BOOTSEL, plug in the USB cable | a USB drive "RP2350" appears (step 9) |
| Resistors 10 kΩ, 47 kΩ | multimeter Ω | within 5% of the value |
| Capacitors 1 µF, 100 nF | print on the part | 1 µF: "1µF" or "105"; 100 nF: "104" |
| Regulator, slide, main valve | thread sizes | G1/4 (the PC4-02 fittings fit) |
| Emergency stop | multimeter in beep mode, on the NC terminals | beeps when released, silent when pressed |
| Compressor | first run with the tank empty (outlet closed) | starts, stops by itself at its cut-off pressure (8 bar for a 6 l silent compressor); note the time from 0 to cut-off |
| | tank holds pressure | after cut-off, outlet closed: the tank gauge drops less than 0.5 bar in 10 minutes |
| | outlet coupler | note the coupler type (Euro/Orion, ISO 6150 B, Rectus 26, …) and buy the matching G1/4 plug nipple |
| | drain valve under the tank | opens and closes; drain the water after every session |

📷 Photo of all parts side by side, with the valve labels readable.

**Compressor delivery.** The air the compressor really delivers (free air) follows from the
first fill: tank volume × cut-off pressure (bar gauge) ÷ fill time. Example: 6 l × 8 bar ÷
60 s = 48 l/min. Also time a refill from the cut-in pressure (where it starts again) to
cut-off. Note both; the full-size arm needs this number (see `docs/full-arm-sizing.md`,
air use).

---

## 2. Tools

- jigsaw or hand saw (wood), hacksaw and file (aluminium)
- drill with wood bits 5 and 8.5 mm, metal bits 5.5 and 8.5 mm, 22 mm Forstner bit
- screwdrivers, spanners 8, 10, 13 mm, hex keys
- wire stripper, small screwdriver for screw terminals
- tape measure, try square, awl or centre punch
- multimeter
- safety glasses

---

## 3. Woodwork: base plate, cheeks and spacer block

Drawings: `out/drawings/cheek.pdf` and `out/drawings/side_view.pdf`.

1. **Saw** from 18 mm plywood. DIY stores often cut to size for free.
   - base plate 400 × 300 mm
   - 2 cheeks 450 × 120 mm
   - 2 blocks 60 × 60 mm (together the 36 mm spacer block)
2. **Mark the holes on both cheeks.** Put them exactly on top of each other and clamp
   them, so the holes line up perfectly in both cheeks.
   - hinge: middle of the width (60 mm), 420 mm from the bottom
   - cylinder pivot: middle (60 mm), 100 mm from the bottom
   - 2 screw holes for the block: 30 mm from the back, 20 and 45 mm high
3. **Drill** with the cheeks still clamped together:
   - Ø10 mm through, at the hinge
   - Ø8.5 mm through, at the cylinder pivot
   - Ø5 mm through, at the screw holes
4. **Bearing seats.** Separate the cheeks. On the **outside** of each cheek, at the
   hinge, drill a 22 mm hole **7 mm deep** with the Forstner bit. The two cheeks are
   mirror images.
   - Press a 608 bearing in. It should be a tight fit: tap it in with a block of wood.
   - If it is loose, fix it with a drop of two-component glue.
5. **Spacer block:** glue the two 60 × 60 blocks together (36 mm thick).
6. **Assembly:**
   - put the spacer block at the back bottom between the cheeks and screw it with
     4 screws 4×40 through the Ø5 holes;
   - fix the cheeks to the base plate with 4 angle brackets. The back of the cheeks is
     90 mm from the back edge of the base plate (the front is 190 mm from the front
     edge); the cheeks are centred across the width.
   - Check with the try square that the cheeks stand square.

📷 Photo of the upright on the base plate, from the side and from the front.

---

## 4. The arm

Drawing: `out/drawings/arm.pdf`.

1. Cut the 40×5 aluminium bar to **450 mm** and file the edges smooth.
2. **Mark the holes** on the centre line (20 mm from the edge):
   - hinge: 20 mm from one end
   - clevis: 150 mm from the hinge hole
   - load bolt: 400 mm from the hinge hole
3. Centre-punch, drill Ø5 first, then **Ø8.5**, and deburr.
4. **Spacer sleeves:** cut four pieces of the 10×1 tube:
   - 2× **15.5 mm** for the arm in the hinge (36 − 5 = 31, split over 2 sides)
   - 2× **7 mm** for the cylinder's rear pivot (36 − 22 = 14, split)
5. **Assembly:** push an M8×80 bolt through the bearings and cheeks, with the sleeves and
   the arm in between: bearing — 15.5 sleeve — arm — 15.5 sleeve — bearing. Tighten the
   lock nut until there is no play but the arm still turns freely.

📷 Photo of the hinge from above. The arm must sit centred between the cheeks and swing
freely up and down.

6. **Load:** 1 kg dumbbell plates on an M8×60 bolt through the load hole, between two
   large washers (M8 × 40 mm), with a nut. One plate for most tests; for more, put them
   alternately left and right of the arm so it does not twist. If the plate's hole is
   much bigger than the bolt, centre it with a short piece of 25 mm conduit or a few turns
   of tape. Tighten well: the plates must not swing or slide.

---

## 5. The cylinder

1. **Measure the pin-to-pin length** with the rod fully retracted: from the centre of the
   rear hole to the centre of the clevis pin. Fit the clevis on the rod first, see step 2.
   - The calculation assumes **311 mm**.
   - If it differs by more than 5 mm, change `CYL` in `params.py` and run `build.py`:
     it changes the range of motion and the calibration.
2. **Clevis on the rod,** in this order: M8 nut — potentiometer bracket (8.5 hole) — M8
   nut — clevis. Screw the clevis about 12 mm onto the rod and lock it with the nuts.
3. **Rear pivot:** push the second M8×80 bolt through the cheek, a 7 mm sleeve, the hole
   at the back of the cylinder, another 7 mm sleeve and the other cheek. The air ports
   point to the **front** (away from the upright). Tighten the lock nut but let the
   cylinder pivot freely.
4. **To the arm:** fix the clevis with its pin in the hole at 150 mm. Fit the circlip or
   split pin.
5. Move the arm by hand all the way up and down. Nothing may touch.
   - Lowest position: about −17°, cylinder fully retracted.
   - Highest position: about +66°, cylinder fully extended.

📷 Photo from the side, with the arm horizontal.

---

## 6. The potentiometer

1. Bend a mounting strip from the 20×3 strip to fit the cylinder tube.
2. Fix the potentiometer to it with its own clips.
3. Clamp the mounting strip to the cylinder tube with two hose clamps, on the **underside**
   (away from the hinge). The potentiometer runs parallel to the cylinder.
4. Fix the ball joint of the potentiometer rod with an M5 bolt to the bracket on the
   cylinder rod.
5. Move the arm all the way up and down.
   - The potentiometer must never reach its own end stop: its stroke is 175 mm, the
     cylinder's 150 mm. Slide it so there is clearance at both ends.
   - Nothing may bind; the ball joint takes up small misalignment.

📷 Photo of the potentiometer on the cylinder, in the lowest and highest positions.

---

## 7. Pneumatics

Diagram: `out/drawings/pneumatics.pdf`. The connection tables are in
`docs/design.md` ("Pneumatic connections").

**Push-in fittings:**
- **Inserting a tube:** cut it square with the tube cutter and push it in firmly up to
  the stop (about 15 mm). Then give the tube a pull.
- **Removing a tube:** press the blue collar and pull.

**Threads:**
- G1/4 and 1/8: PTFE tape, 3–4 turns in the direction of the thread. Hand-tight, then a
  quarter turn with a spanner.
- M5 on the valves: not too tight, the sub-plate is plastic. The fitting's rubber ring
  seals.

**Assembly:**
1. **Prepare the valves** (see the table in the design document):
   - **fill valves V1, V3:** P = supply, A = to the chamber, **R = blanking plug**
   - **vent valves V2, V4:** P = from the chamber, A = silencer, **R = blanking plug**
   - Label each valve: V1 fill A, V2 vent A, V3 fill B, V4 vent B.
2. **Mount the valves close to the cylinder,** on the spacer block or a strip of wood.
   Keep every tube between valve and cylinder **shorter than 30 cm**.
3. **Chamber A** is the port at the back of the cylinder (piston side), **chamber B** the
   port at the front (rod side).
4. **Per chamber:** one tee to the fill valve, the vent valve and the cylinder port, and a
   second tee to the pressure sensor (screwed into a PCF4-02).
5. **Supply:** compressor — regulator — shut-off slide — main valve P → A — tee — to P of
   V1 and V3. The main valve's R port stays open: that is where the supply vents on an
   e-stop.
6. Do **not** fit the flow restrictors yet. They are for later (the comparison).

📷 Photo of the complete pneumatics, with the labels readable.

**First leak test with soapy water** (only after steps 8 and 9, when the e-stop works):
1. Regulator at 2 bar, shut-off slide open.
2. Main valve on: the e-stop is released and the 24 V is on.
3. Brush soapy water over every fitting. Bubbles = leak. Cut and re-insert the tube, or
   re-tape the thread.

---

## 8. Electronics

Diagram: `out/drawings/wiring.png`. Connection list: `out/drawings/wiring_list.png`.

**Work in this order and test after each step.** Only plug the 24 V adapter into the
mains when the steps say so.

1. **Pico and ULN2803A** on the breadboard. Put the ULN2803A across the middle gap with
   the notch to the left. Pin 1 is then bottom left (often marked with a dot); pins 1–9
   run along the bottom, pins 10–18 back along the top.
2. **Ground:** Pico GND, ULN2803A pin 9, LM7805C pin 2 and the adapter's minus together on
   the blue rail of the breadboard.
3. **Control wires:** GP2 → IN1 (pin 1), GP3 → IN2 (pin 2), GP4 → IN3 (pin 3),
   GP5 → IN4 (pin 4).
4. **24 V and emergency stop:**
   - Adapter plus via the DC jack to the **NC contact** of the e-stop.
   - The other side of the e-stop is "+24 V after e-stop". It goes to ULN2803A pin 10
     (COM) and to the red wire of all four VQ110 coils.
   - One side of the main valve also connects to "+24 V after e-stop". The other side of
     the main valve goes to GND.
5. **Coils:** black of V1 → OUT1 (pin 18), V2 → OUT2 (pin 17), V3 → OUT3 (pin 16),
   V4 → OUT4 (pin 15). **Mind the polarity:** the coil plugs contain an LED and a
   suppressor that work in one direction only.
6. **LM7805C:**
   - IN (pin 1) to the 24 V **before** the e-stop, with the 1 µF from IN to GND.
   - OUT (pin 3) becomes +5 V, with the 100 nF from OUT to GND.
   - Pin order, text facing you and legs down: IN – GND – OUT.
7. **Pressure sensors:**
   - red to +5 V, black to GND
   - signal via **10 kΩ** to GP27 (sensor A) and GP28 (sensor B)
   - from GP27 and GP28 each a **15 kΩ** to GND, and a **100 nF** to GND. No 15 kΩ? Use
     **3× 47 kΩ in parallel** (15.7 kΩ). Do not go above a ratio of 0.6 (bottom ÷
     (top + bottom)), or more than 3.3 V reaches the Pico pin at 5 V.
8. **Potentiometer:**
   - ends to **3V3** (Pico pin 36) and **GND**
   - wiper to **GP26**, with a 100 nF to GND

📷 Photo of the breadboard from above, sharp enough to follow the wires.

**First test, without compressed air** (shut-off slide closed):
1. **Measure 5 V:** adapter in, e-stop released. Measure OUT of the 7805: 4.9–5.1 V.
2. **Sensor voltage at the Pico pins:** measure GP27 and GP28 to GND. It must be below
   3.1 V, otherwise the divider is wrong. At 0 bar it is about 0.3 V.
3. **Make the valves click:** see step 9 (software), command `valve 1 0 0 0`. You hear V1
   click and see its LED. Test all four this way, then the e-stop: pressed = all quiet.

---

## 9. Software

### On the Pico (MicroPython)

1. **Install MicroPython:**
   - download MicroPython for your board from micropython.org (a `.uf2` file): the
     **Raspberry Pi Pico 2 W** build (`RPI_PICO2_W`) for the Wi-Fi version, or the
     **Pico 2** build (`RPI_PICO2`) without Wi-Fi. The wrong build does not start;
   - solder the header pins on first if your Pico came without them;
   - hold the BOOTSEL button and plug in the USB cable. The Pico shows up as a USB drive;
   - drag the `.uf2` file onto it. The Pico restarts by itself.
2. Install **Thonny** (thonny.org). Bottom right, choose "MicroPython (Raspberry Pi Pico)".
3. **Copy the firmware:** put the four files from `firmware/` on the Pico: `main.py`,
   `control.py`, `config.py` and `hw.py`. In Thonny: open the file, then "Save as…" →
   "Raspberry Pi Pico".
4. Press Stop/Restart in Thonny. At the bottom you see `OK,started`. Type `help` for the
   commands.

`config.py` is generated from `params.py` (`python gen_config.py`), so do not edit it by
hand.

### On the PC (Python 3.10 or newer)

```
cd test1/host
pip install -r requirements.txt
python logger.py              # finds the Pico itself; otherwise --port COM5 or /dev/ttyACM0
```

Close Thonny first: only one program at a time can talk to the Pico.

**Main commands** (also in `help`):

| Command | What |
|---|---|
| `off` | close all valves |
| `valve 1 0 0 0` | open V1 (manual, duty 0..1 per valve) |
| `pressure 2 2` | control both chambers to 2 bar |
| `angle 20` | arm to 20° |
| `move 20` | arm to 20°, fast and smoothly (T8) |
| `load 1`, `speed 0.8` | load on the arm in kg, and the speed of `move` (1 = as tuned) |
| `gain 0.5` | strength of the position control (1 = as tuned for 1 kg; 0.5 without load) |
| `bang 20` | on/off control to 20° (T2) |
| `stiffness 4` | sum of the chamber pressures |
| `zero`, `cal_pressure 3`, `cal_pos in`, `cal_pos out`, `save` | calibration (step 10) |

**Safety in the software:**
- If the PC sends nothing for half a second, all valves close. The logger and the test
  script therefore send `ping` every 0.2 s.
- The hardware watchdog starts at the first motion command. If the program hangs, the
  Pico resets itself, with all valves closed.

---

## 10. Calibration

Do this once, and again after moving the potentiometer or replacing a sensor.

1. **Pressure zero:** shut-off slide closed. Type `valve 0 1 0 1` (both vent valves open)
   and leave it like that up to and including step 3. Type **`zero`**.
2. **Potentiometer, bottom:** move the arm by hand all the way down (cylinder fully in).
   The arm moves freely because both chambers are open to the atmosphere. Type
   **`cal_pos in`**.
3. **Potentiometer, top:** move the arm by hand all the way up (cylinder fully out). Type
   **`cal_pos out`**, lower the arm gently and type `off`.
4. **Pressure gain:**
   - regulator at **3.0 bar**, shut-off slide open;
   - type **`valve 1 0 1 0`**: both chambers fill to 3 bar. With the load on, the arm
     stays down or moves a little; that is fine. Wait 3 seconds;
   - read the gauge and type **`cal_pressure 3.0`** (or whatever the gauge shows);
   - type `off`.
5. **`save`**: the calibration goes to `cal.json` on the Pico.
6. **Check:**
   - move the arm by hand to horizontal. The logger should show an angle of about 0°;
     check with a spirit level;
   - the gauge and the measured pressure must agree within 0.1 bar.

📷 Screenshot of the logger with the arm horizontal.

---

## 11. The tests

Start: `python tests_t0_t8.py T0` (and so on), or `python tests_t0_t8.py all`.
Each test stores its run, plot and outcome in `host/results/`.

| Test | Pressure | Load | What | Passed if |
|---|---|---|---|---|
| T0 leak test | 3 bar | none (`gain 0.5`) | arm to 20°, all valves closed, measure 60 s | pressure drop < 0.1 bar |
| T1 valves | 3 bar | – | open each valve for 10 ms, sample the pressure fast | response < 10 ms |
| T2 on/off | 3 bar | 1 kg | 0° → 30° → −5° with fully open/closed valves only | comes to rest within ±3 mm |
| T3 PWM control | 5 bar | first none (`gain 0.5`), then 1 kg | 0° → 30° → −5° | overshoot < 5 mm, settled within 1 s, error < 1 mm |
| T4 repeatability | 5 bar | 1 kg | 10× to 20°, alternately from above and below | spread < ±1 mm |
| T5 holding | 5 bar | 1 kg | 60 s at 30° | deviation < 1 mm |
| T6 stiffness | 5 bar | 1 + 1 kg | at 20°, valves closed, add a plate; chamber pressure sum 2 and 5 bar | clearly less deflection at 5 bar |
| T7 load ratio | 5 bar | 1 → 5 kg | repeat T3, one plate more each time | highest load at which T3 passes |
| T8 fast and smooth | 5 bar | 1 kg; then 2 kg at 80% speed | `move` to preset angles: 30°, −5°, 50°, 10°, and a new target during a move | per move: following the profile within 3 mm, overshoot < 2 mm, within ±1.5 mm at most 0.2 s after the profile ends, error at rest < 1 mm |

**Without load first:** the arm first moves without a plate (T0, then T3a), only then with
1 kg. The control is tuned for 1 kg; without load the arm is twelve times easier to turn
and the same control makes it shake (in the simulation about 7 Hz, ±6 mm). The script
therefore sends `gain 0.5` for the runs without load, and `gain 1` once the plate is on.

The simulation's expectations are in `out/sim/results.json` and in the README. If the
real measurement differs a lot, that is useful information in itself, for example about
the cylinder's friction.

**T8, the last test:** the arm goes to a series of preset angles, fast and smoothly; the
test script sends them. The Pico plans a smooth profile (speed and acceleration build up and die out gradually,
at most 170°/s and 1550°/s², 10% slower than the fastest profile that still passes in
the simulation) and pushes ahead with the force that profile needs:
gravity, the acceleration of arm and load, and the cylinder's friction.
- The feedforward needs the weight of the load: the script sends it (`load 1`). In the
  simulation 10% off still passes; 20% too light does not.
- With 2 kg the moves are slower (`speed 0.8`): at full speed the move to 50° does not
  settle in time. A heavier load gets a lower speed rather than different tuning.
- Later the target can come from a knob with a button to start the move (order 6 in the
  bill of materials, not needed now).

**After T7:** fit the flow restrictors between the tee and the fill valves and repeat T3
with the restrictors ¼, ½ and ¾ closed. This shows what a smaller valve does to speed and
precision. Mark each screw so you can find a setting again.

---

## 12. Troubleshooting

| What you see | Likely cause | What to do |
|---|---|---|
| Valve does not click | polarity reversed, or e-stop pressed | red to +24 V after e-stop, black to OUT; release the e-stop |
| Valve always open | R port not plugged, or P and A swapped | blanking plug on R; see the table in step 7 |
| Pressure slowly drops (T0) | leaking fitting | soapy-water test, cut the tube square again |
| Pressure reads 0 while the gauge shows 3 bar | sensor without +5 V or wrong wire | measure 5 V on the red wire; signal on yellow/green |
| Angle jumps or is noisy | loose potentiometer wire, or no 100 nF on GP26 | check the connections |
| Arm oscillates around the target | control too strong for this load (or friction differs from the simulation) | try `gain 0.7` or `gain 0.5` (takes effect at once); to keep it, lower `KP_FORCE`, `KI_FORCE` and `KD_FORCE` in `params.py`, run `python gen_config.py`, copy config.py again |
| `ERROR,over-pressure` | regulator above 6 bar | turn the regulator down |
| `ERROR,no contact with the PC` | logger stopped or USB unplugged | normal behaviour; start again |
| The Pico keeps restarting | watchdog after stopping in Thonny | normal: after 2 s it runs again, with all valves closed |
| Linux: the Pico is in `lsusb` (2e8a:0005) but there is no `/dev/ttyACM0` | minimal (cloud/VM) kernel without the USB serial driver | `sudo apt install linux-image-extra-virtual`, then `sudo modprobe cdc_acm`; add yourself to the `dialout` group |
| Data lines (`D,…`) with jumping values before the sensors are connected | the analog inputs are open | normal; they settle once the sensors and the 100 nF are in place |

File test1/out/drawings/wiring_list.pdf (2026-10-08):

from | to | note
Pico GP2 | ULN2803A IN1 (pin 1) | V1 fill A
Pico GP3 | ULN2803A IN2 (pin 2) | V2 vent A
Pico GP4 | ULN2803A IN3 (pin 3) | V3 fill B
Pico GP5 | ULN2803A IN4 (pin 4) | V4 vent B
ULN2803A OUT1–OUT4 (pin 18–15) | black wire V1–V4 | red of V1–V4 → +24 V after e-stop
ULN2803A COM (pin 10) | +24 V after e-stop | flyback diodes
ULN2803A GND (pin 9) | GND (adapter minus)
+24 V adapter | e-stop NC | → +24 V after e-stop
+24 V after e-stop | main valve 3V210-08 | other side of coil → GND
+24 V adapter (before e-stop) | LM7805C IN (pin 1) | 1 µF IN–GND
LM7805C OUT (pin 3) | red wire pressure sensors A and B | 100 nF OUT–GND
pressure sensor A signal | 10 kΩ → GP27, 15 kΩ GP27→GND | 100 nF GP27→GND
pressure sensor B signal | 10 kΩ → GP28, 15 kΩ GP28→GND | 100 nF GP28→GND
potentiometer ends | Pico 3V3 (pin 36) and GND
potentiometer wiper | Pico GP26/ADC0 | 100 nF GP26→GND
all GND | Pico GND, ULN pin 9, 7805 pin 2, adapter minus, sensor black wires one common ground

### Wiring test 1 — connection list

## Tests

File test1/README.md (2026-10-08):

# Test 1 — pneumatic arm with one degree of freedom

Test 1

## Project description

This is the first and smallest test of the [pneumatic-arm](../README.md) project: an
accessible robot arm that works with cylinders, like muscles, and is controlled with
feedback by a program or AI.

Test 1 answers one question: **can an ordinary pneumatic cylinder with cheap on/off
valves move an arm to a chosen angle and keep it there, fast and to the millimetre, also
with a load on it?**

**The set-up:**
- a 45 cm arm on a hinge, moved by one Ø20 × 150 mm cylinder;
- per cylinder chamber a fill valve and a vent valve (SMC VQ110U, 4 pieces), driven with
  PWM;
- a linear potentiometer for the position, a pressure sensor per chamber, and a
  Raspberry Pi Pico 2 that controls everything 250 times per second.

**What it delivers:**
- the answer whether pneumatics work for this arm;
- the number that sets how big the shoulder and elbow cylinders have to be (test T7);
- the control software that carries over to the real arm.

**Targets** (test T3): overshoot < 5 mm, settled within 1 s, error < 1 mm. In the
simulation the overshoot and error are met; settling within ±1 mm is borderline; see the
[results](out/sim/results.md).

**Last test** (T8): the arm moves to a series of preset angles fast and smoothly: in the
simulation 30° in 0.4 s, following a smooth profile within 3 mm, without overshoot worth
mentioning.

## What is in this package

| Folder / file | Contents |
|---|---|
| [`docs/manual.md`](docs/manual.md) | **Start here.** Incoming inspection, building, wiring, software, calibration, tests T0–T8, troubleshooting |
| [`docs/design.md`](docs/design.md) | Why it is built this way: valves, pneumatics, electronics, mechanics, control, simulation |
| [`docs/bom.md`](docs/bom.md) | Bill of materials with items, variants, quantities and prices; also as CSV |
| `out/drawings/` | Side view, cheek and arm dimension drawings, wiring diagram, connection list, pneumatic diagram (PNG + PDF) |
| `out/cad/` | CAD: STEP per part and of the assembly, STL, DXF profiles, GLB (3D in a browser) |
| `out/sim/` | Simulation results, plots and renders |
| `params.py` | **All dimensions and settings.** Everything else is generated from it |
| `cad/` | CadQuery model (`parts.py`) and export (`export.py`) |
| `sim/` | MuJoCo model (`model.py`), pneumatics model (`pneumatics.py`), scenarios (`run.py`) |
| `firmware/` | MicroPython for the Pico 2: `main.py`, `control.py` (controller), `hw.py`, `config.py` (generated) |
| `host/` | PC tools: `logger.py` (manual control + recording), `tests_t0_t8.py` (tests T0–T8, automated), `analysis.py` |
| `tests/test_firmware.py` | Runs the firmware on a PC with simulated hardware |
| `build.py` | Regenerates everything and builds the bundle |

## Quick start

- **Build:** follow [the manual](docs/manual.md) from top to bottom.
- **Run the simulation:**
  ```
  pip install -r requirements.txt
  python sim/run.py --render
  ```
- **Change something** (a dimension, a gain): edit `params.py` and run
  `python build.py`. CAD, simulation, firmware settings, drawings and bill of materials
  are then in sync again.

## Status

| Part | Status |
|---|---|
| Design, CAD, drawings | done |
| Simulation and tuning | done; at 250 Hz the moves are fine, settling within ±1 mm is borderline (T3, T8) |
| Firmware and PC tools | done, tested with simulated hardware; runs on the Pico (no sensors yet), 250 Hz measured |
| Parts | AliExpress ordered 2026-10-04; electronics and compressor received; DIY-store parts still to buy |
| Build and tests T0–T8 | to do |

## Open and free to rebuild

Designed to be rebuilt with ordinary parts. All sources (CadQuery, MuJoCo, MicroPython,
Python) are plain text and open; no paid software is needed. See the
[licence](../LICENSE).

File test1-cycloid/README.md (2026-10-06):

# Test 1 reference — printed cycloidal drive (on hold)

**On hold.** The arm is driven by cylinders on levers: a plain hinge carries the arm and
the cylinder only pushes. A gearbox in the joint has to transmit the torque and carry the
arm at the same time, which needs precise bearings and fits. The printed cycloid answers
no question the arm needs, so it is kept here, ready to print, but is not on the path to
the arm.

A second electric reference for [test 1](../test1/README.md), next to the
[harmonic drive](../test1-harmonic-drive/README.md): the same arm, load, motor and angle
sensor, but with a cycloidal drive printed in PLA. Only the gearbox differs, so the
comparison shows what printing costs in backlash, stiffness and strength.

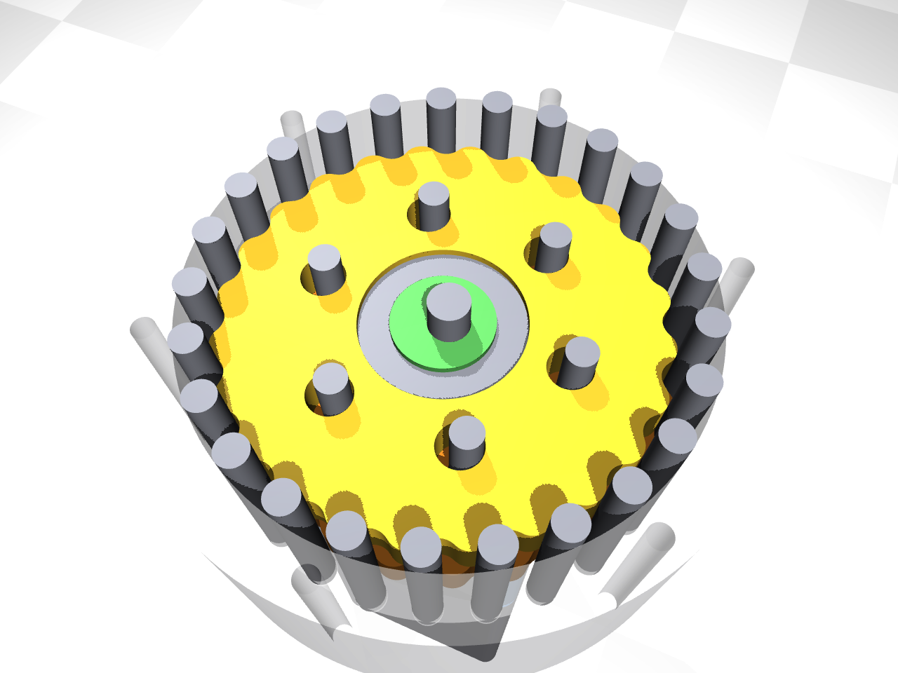
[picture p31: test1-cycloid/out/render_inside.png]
Inside: disc, housing pins and output pins


## How it works

- The motor turns a double eccentric (cam) on the input shaft, 1.2 mm off centre.
- Each disc rolls around inside a ring of 25 steel pins. The disc has 24 lobes, so per
  input turn it moves back by one lobe: **24:1**, output turning the other way.
- Two discs run half a turn apart, so their forces balance and the drive runs smoothly.
- Six steel pins through oversized holes in the discs (hole = pin + 2 × eccentricity) take
  the slow rotation off the discs and turn the two carriers, which are the output.
- Both carriers run in a 6808 bearing in the housing; the input shaft runs in a 608
  bearing in each carrier, so the motor shaft carries no load (flexible coupling).

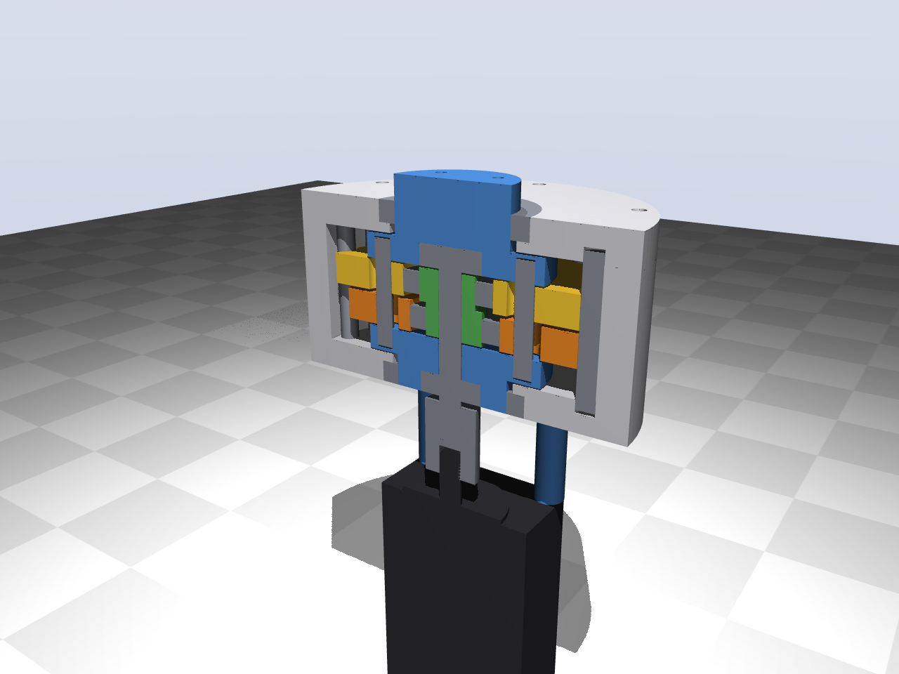
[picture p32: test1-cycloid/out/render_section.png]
Section


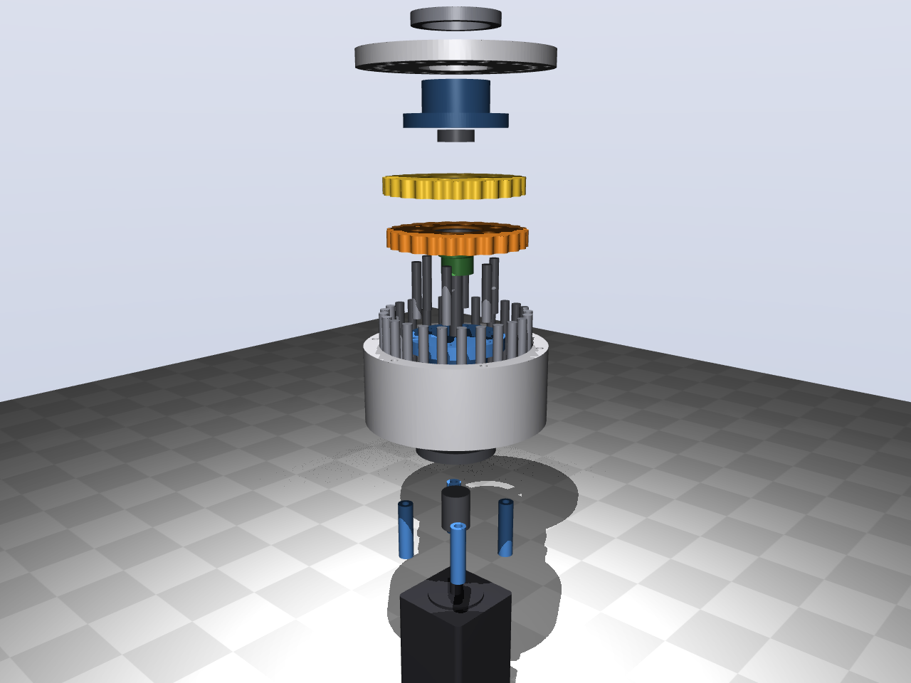
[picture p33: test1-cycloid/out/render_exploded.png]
Exploded


## Sizing (`python cyparams.py`)

| | 1.5 kg | 3 kg (T5) |
|---|---|---|
| Torque at the joint (horizontal, 180°/s²) | 7.3 Nm | 13.9 Nm |
| Torque at the motor (efficiency 75%) | 0.40 Nm | 0.77 Nm |
| Largest pin force | 19 N | 37 N |
| Contact stress steel pin on PLA lobe | ≈ 28 MPa | ≈ 39 MPa |

- PLA takes about 60 MPa in compression (less when printed), so 3 kg is within reach
  but not with a large margin. The breaking test measures the real limit.
- Output speed about 150°/s with the motor at 600 rpm.
- Size Ø116 × 67 mm plus the motor.

## Printing (PLA)

**First print `fit_test.stl`** (about 30 minutes). It holds the drive's real fits: the
seats for the 6808, 6804 and 608 bearings, the pegs that go into the 6808 and 6804 bores,
and three Ø6 pin holes (−0.05 / +0.10 / +0.15). Press the bearings and pins in and adjust
`FIT` in `cyparams.py`, then regenerate (`python cad/cycloid.py --stl`):

| Fit | Now | Too tight → | Too loose → |
|---|---|---|---|
| `seat`: bearing into a printed hole | hole = OD + 0.15 | larger | smaller |
| `journal`: printed peg into a bearing | peg = ID − 0.10 | more negative | towards 0 |
| `pin`: dowel pin into a printed hole | hole = Ø6 + 0.10 | the hole that fits best | |

The bearings should go in with light pressure (a vice or a few taps), not fall in and not
need force that cracks the part.

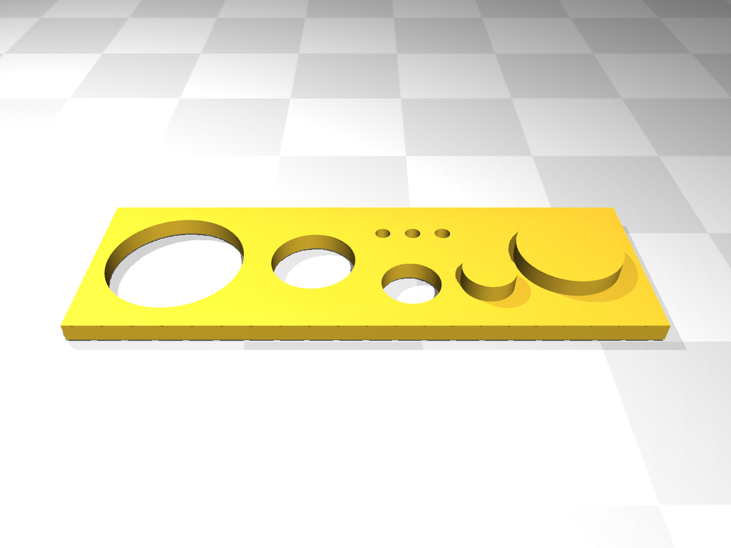
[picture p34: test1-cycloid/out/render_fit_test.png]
Fit test


| Part | Qty | Orientation | Notes |
|---|---|---|---|
| `disc_0.stl`, `disc_1.stl` | 1 each | flat | 100% infill (or ≥ 6 perimeters); 0.2 mm layers; they differ (output holes half a lobe apart) |
| `housing.stl` | 1 | open side up | pin holes blind, Ø6 + `pin` |
| `cover.stl` | 1 | inner face down | |
| `carrier_rear.stl`, `carrier_front.stl` | 1 each | flange down | output pin holes Ø6 + `pin`, press fit |
| `cam.stl` | 1 | upright | glue on the shaft with epoxy |
| `standoff.stl` | 4 | upright | |

Print one disc first and check it against a few pins: they should roll without play and
without force. The profile clearance is `CLEARANCE` in `cyparams.py` (0.10 mm).

## Bought parts

| Part | Qty |
|---|---|
| Dowel pin Ø6 × 45 (ISO 8734 / DIN 6325) | 25 |
| Dowel pin Ø6 × 35 | 6 |
| Shaft Ø8 × 62 mm (cut from 8 mm linear rod) | 1 |
| Ball bearing 6808-2RS (40 × 52 × 7) | 2 |
| Ball bearing 6804-2RS (20 × 32 × 7) | 2 |
| Ball bearing 608-2RS (8 × 22 × 7) | 2 |
| Flexible coupling 8–8 mm, Ø19 × 25 | 1 |
| M4 × 70 + nut (housing) | 6 |
| M5 × 60 + nut (motor) | 4 |
| M4 × 10 (output flange, tapped in PLA) | 4 |
| Grease (PTFE or lithium) | |
| Motor: NEMA23 closed-loop stepper, shared with the harmonic drive reference | (1) |

## Tests

1. Tests T3–T7 from the [test 1 manual](../test1/docs/manual.md), as for the other two
   set-ups.
2. Backlash: torque back and forth at the output, angle from the AS5600. New, and again
   after a few thousand movements.
3. Breaking test: increase the load until a lobe skips or the disc deforms; this gives the
   real torque limit of printed PLA.

## Files

`cyparams.py` (dimensions, sizing), `cad/cycloid.py` (CadQuery parts, assembly, clash
check, `--stl`, `--step`), `render.py` (renders; `--video` for the motion, not kept in
git), `out/stl/` (parts to print), `out/step/` (STEP per printed part and
`assembly.step` with all parts, coloured, input at 0°). The disc outline is a smooth
spline through the exact cycloid profile.

## Status

On hold (see the top). Designed with print fits and clash-checked over a full input turn
(gap 0.10 mm to the housing pins, 0.20 mm to the output pins). Not printed. If picked up
again: print the fit test first, then design the mounting on the test 1 stand.

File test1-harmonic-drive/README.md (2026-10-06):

# Test 1 reference — the same arm on a harmonic drive

The electric counterpart of [test 1](../test1/README.md): the same arm, load and base,
but the joint is driven the way most robot arms are driven: a motor with a harmonic
drive (strain wave gear) in the joint. Cobots (Universal Robots, Franka, Kinova) use
this in every joint; industrial robots use it in the wrist.

It answers: **how does the pneumatic joint compare with the standard electric joint on
precision, speed, stiffness, behaviour when pushed, cost and weight?**

## Set-up

- **Gear:** harmonic drive size 17, ratio 100:1, cup type (CSF-17 pattern; clones are
  widely available). Zero backlash: 1 arcmin is 0.12 mm at the load.
- **Motor:** NEMA23 closed-loop stepper (motor with encoder and driver), step/dir from
  the Pico. The flange takes a servo motor of the same frame size later, for the full
  cobot set-up with torque control.
- **Arm, load, base:** as test 1 (flat bar 40×5, 450 mm, load hook at 400 mm, plywood
  cheeks).
- **Sensor:** an AS5600 magnetic angle sensor on the joint. Test 1 gets the same sensor,
  so both are measured the same way (test 1 itself measures the cylinder length).

## Sizing (`python hdparams.py`)

| | 1.5 kg | 3 kg (T5) |
|---|---|---|
| Gravity torque, arm horizontal | 6.4 Nm | 12.3 Nm |
| Arm inertia / motor rotor seen through the gear | 0.26 / 0.28 kg·m² | 0.50 / 0.28 kg·m² |
| Torque at 180°/s², arm horizontal | 8.1 Nm | 14.7 Nm |
| Torque at the motor (efficiency 70%) | 0.12 Nm | 0.21 Nm |

- The gear's limit for repeated peak torque is 54 Nm, also above the 21 Nm the cylinder
  of test 1 can deliver.
- The motor's rotor, multiplied by 100² through the gear, weighs as much as the arm with
  1.5 kg. This is typical for geared joints and one of the things the comparison shows.
- Output speed about 36°/s (motor at 600 rpm).

The [printed cycloidal drive](../test1-cycloid/README.md) (on hold) would use the same
motor, so only the gearbox would differ.

## Comparison

Both set-ups run the tests of the [test 1 manual](../test1/docs/manual.md) with the same
criteria:
- step response (T3): overshoot, settling time and error;
- load (T7): the largest load that still meets the criteria;
- stiffness (T6): deflection under a push;
- also speed, behaviour when the arm hits something, energy use, cost and weight.

## Status

Folder created; sizing done. Next: CAD with renders, simulation with the same tests,
bill of materials.

Open: ratio 100:1 or 50:1 (twice the speed and a quarter of the rotor inertia, at
lower peak torque).

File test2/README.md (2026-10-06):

# Test 2 — 2-DOF joint (concept)

Concept of the joint from [docs/2dof-joint.md](../docs/2dof-joint.md), built on test 1:
the hinge becomes a universal joint (pitch + roll) and two cylinders drive it. Ø20 like
test 1, but with 200 mm stroke (MAL20×200), and the upright is 100 mm taller.

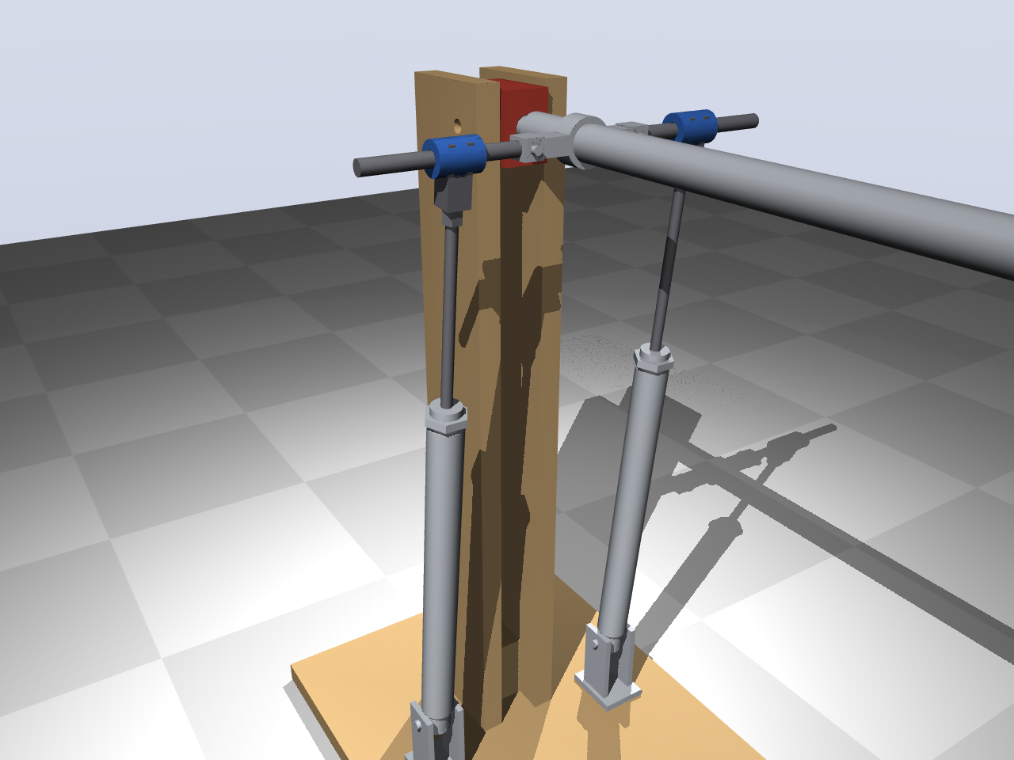
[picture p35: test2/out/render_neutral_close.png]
Concept


**Mechanism (concept B, from the customer's sketch):**
- A hub on the arm axis, 90 mm from the joint, carries two hinges (axis parallel to the
  arm, ±90°), 40 mm left and right of the axis.
- From each hinge a horizontal bar (Ø10) runs outward through a sleeve on the rod end of
  a cylinder. The sleeve lets the bar turn about its own axis and slide sideways.
- The joint sits 520 mm above the base plate (test 1: 420). The cylinders stand almost
  upright (within 6°) under the hub, 90 mm to the sides, on low clevis brackets
  (pivot 40 mm in front of the joint, 60 mm above the plate).
- The cheeks end 25 mm in front of the joint, so the hub clears them with the arm down.
- Both cylinders out: pitch up. One out, one in: roll about the arm's own axis.

**Range (stroke, bar length and a collision check with `python cad/model.py --clash`):**

| Pitch | Roll reachable | Pitch lever | Pitch torque, 2 × Ø20 at 5 bar |
|---|---|---|---|
| −60° | ±90° (no collision only at roll 0) | 46 mm | 15 Nm |
| −45° | ±90° | 67 mm | 21 Nm |
| 0° | ±90° | 89 mm | 28 Nm |
| +45° | ±90° | 61 mm | 19 Nm |
| +75° | ±65° | 26 mm | 8 Nm |

Design range: pitch −45° … +75° (120°) with roll ±65°, down to −60° without roll. A
1.5 kg load at 400 mm needs at most 6.5 Nm, so the reserve is at least 3.9× over the
whole range. The roll torque scales with cos(roll); about ±65° is the useful roll range.
Near 90° the cylinders point through the joint: the arm needs a **mechanical end stop at
about 80°**.

Why upright cylinders: the angular range of a cylinder on a lever is set by stroke and
lever length, and an inclined cylinder wastes part of the stroke. With the cylinders
leaning at least 35°, the same 200 mm stroke reaches only −45° … +45° with less torque.

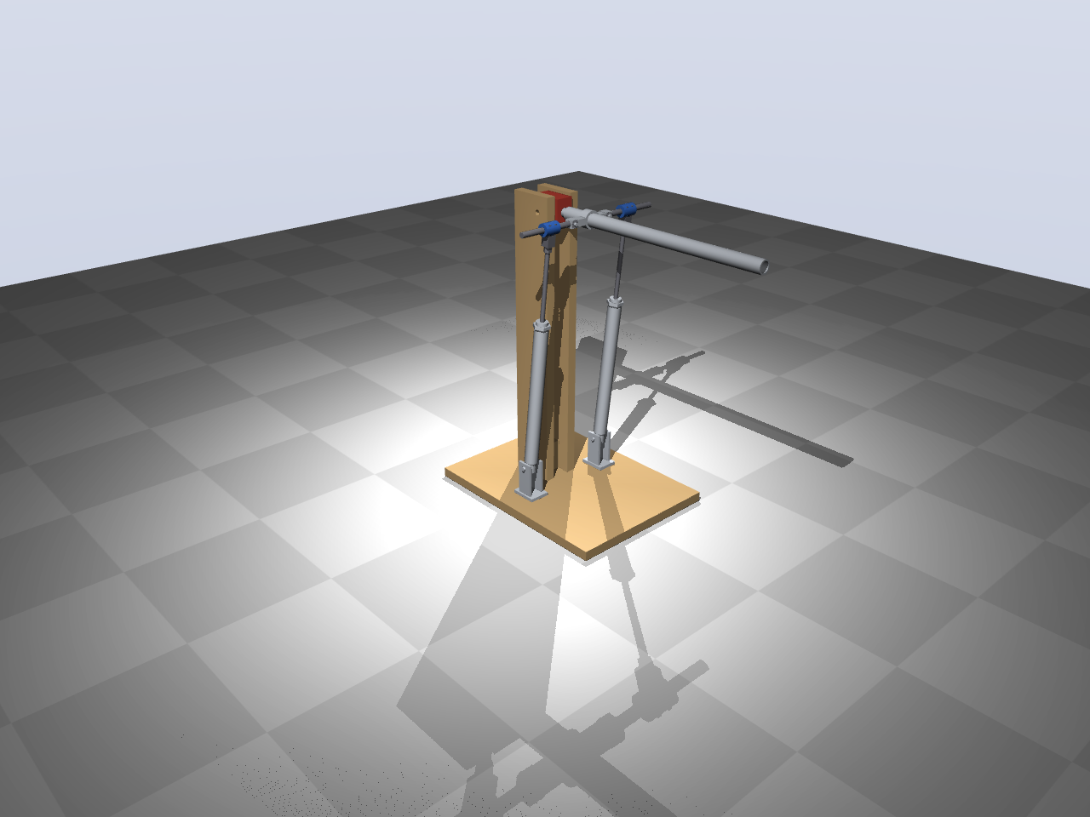
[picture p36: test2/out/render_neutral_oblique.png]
Arm horizontal


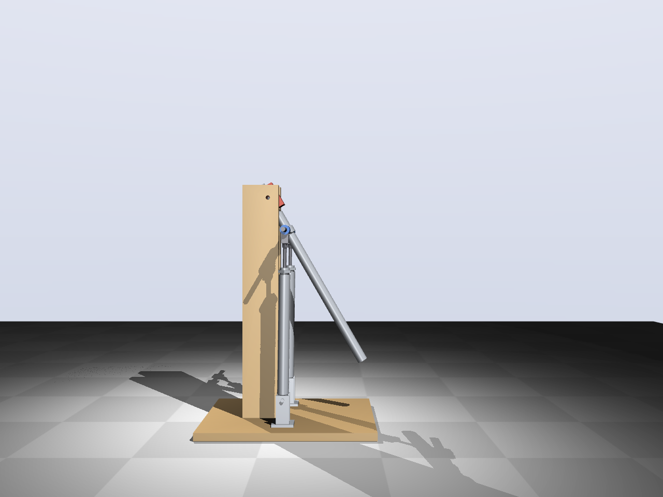
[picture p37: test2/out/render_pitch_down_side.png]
Arm down −60°


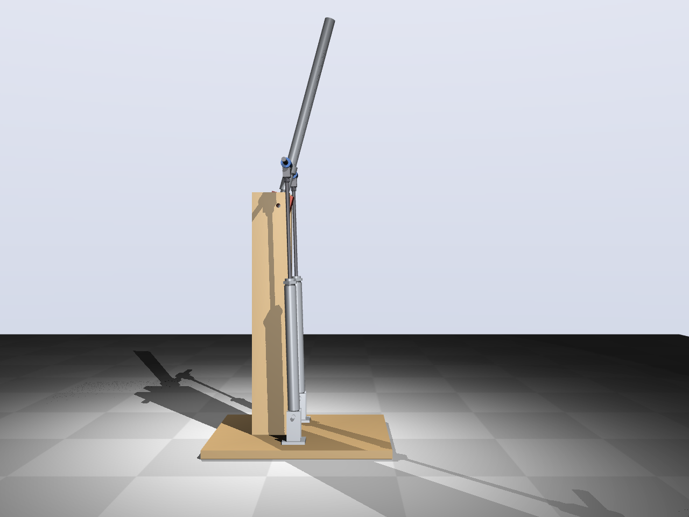
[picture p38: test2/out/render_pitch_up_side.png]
Arm up +75°


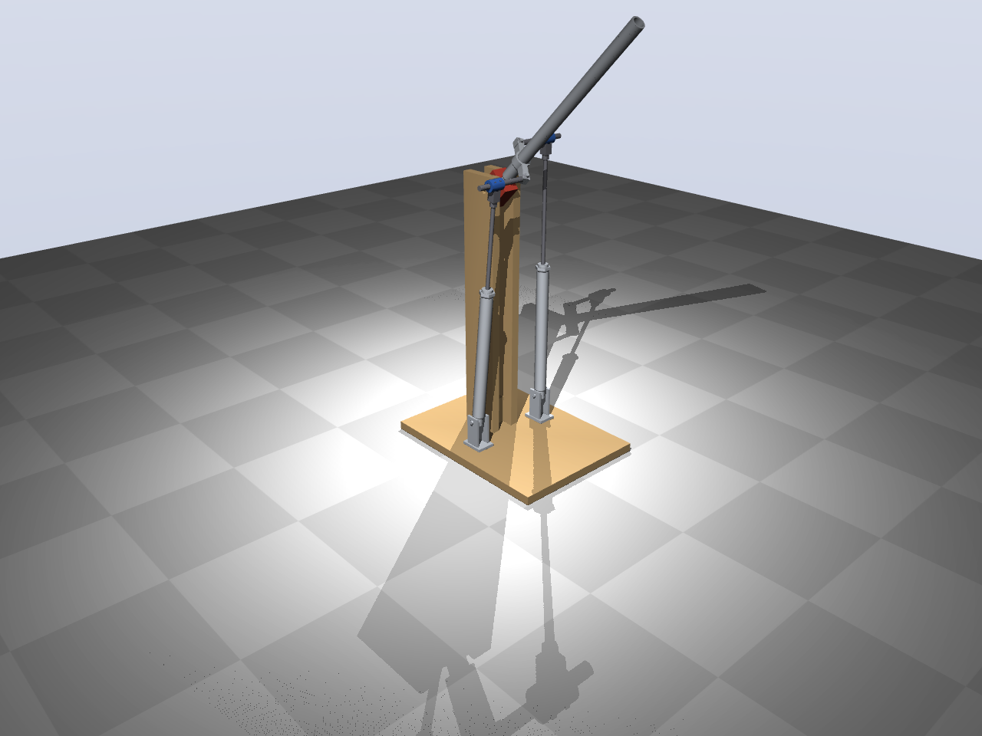
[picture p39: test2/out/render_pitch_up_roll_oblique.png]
Pitch 45°, roll 65°


## Variant: cross block on a fixed bar

In concept B the bar is hinged on the hub and the cylinder force enters it 50–73 mm from
that hinge. The hinge cannot take the resulting moment, so the sleeve does, and it ends up
as bending in the cylinder rod: about 8 Nm at full force (11.5 Nm at 65° roll).

The variant in `cad/cross_block.py` removes that offset:
- the bar is fixed to the hub (no hinge) and ends 45 mm from the arm axis;
- a block turns on the bar at that spot (nothing slides);
- a fork on the cylinder rod holds the block with a pin square to the bar.

Bar + block + fork form a small universal joint whose centre lies on the bar, so the
cylinder force passes through it and the rod only sees push and pull. The cheeks get a
round top around the joint and stop at the joint in front.

Because the cross block moves sideways when rolling, the cylinders no longer stay in their
own plane: at the bottom they swing −5° … +7° forward/back and up to 4° sideways (inwards
only). The bottom mount is therefore a second small universal joint that uses the standard
rear eye of the MAL cylinder:
- the rear eye sits on an M8 pin along y between two fork plates (forward/back);
- the fork has a tongue 26 mm lower that swings on an M8 bolt along x between two plates
  on a foot (sideways).

Seen from the front the eye cannot turn on its pin, so the fork simply leans with the
cylinder and the force still runs along the cylinder axis. The rod can turn in the barrel,
so the rod fork lines itself up with the cross block.

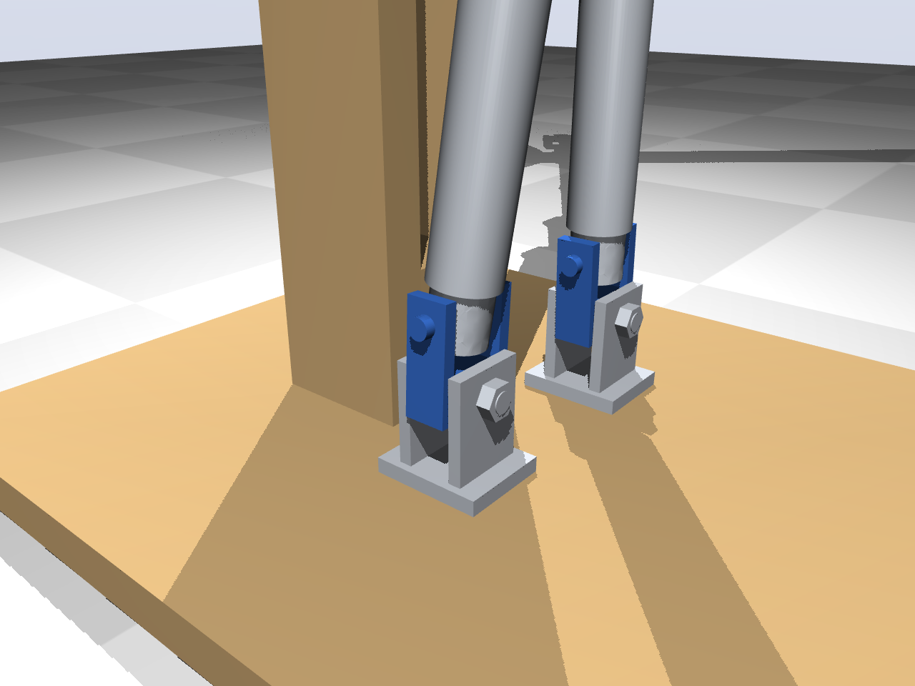
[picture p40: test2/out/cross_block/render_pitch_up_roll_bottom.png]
Bottom joint, pitch 30°, roll 65°


Clash-free roll per pitch (stroke and parts): ±55° at −60°, ±65° from −50° to +45° (±55°
around 0°, where the fork meets the bar), ±45° at +50°, ±15° at +60° … +75°.

Cross block, close

Cross block, pitch 30°, roll 65°

Files: `t2params.py` (dimensions), `cad/model.py` (CadQuery, concept B),
`cad/cross_block.py` (variant), `render.py` (renders and STEP; `--cross-block` for the
variant, output in `out/cross_block/`), `video.py` (the variant moving through its range,
MP4s in `out/cross_block/`, not kept in git). Install with `pip install -r requirements.txt`.

Status: concept for discussion, not yet worked out or simulated.

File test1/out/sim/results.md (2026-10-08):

# Simulation of test 1 — results

Load 1.0 kg, supply 5.0 bar, tuning from `params.py`. T3 criteria: overshoot < 5 mm, settled (within ±1 mm) within 1 s, error < 1 mm.

## T3 PWM control and T2 on/off control

| Step | Overshoot (mm) | Settling (s) | Error (mm) | Passed |
|---|---|---|---|---|
| PWM, no load, gain 0.5: 0° → 30° | 1.49 | 0.544 | 0.15 | yes |
| PWM, no load, gain 0.5: 30° → −5° | 1.67 | 0.636 | 0.33 | yes |
| PWM, no load, gain 1: 0° → 30° | 9.99 | 1.98 | 3.61 | no |
| PWM, no load, gain 1: 30° → −5° | 15.77 | 1.996 | 4.86 | no |
| PWM, 1 kg: 0° → 30° | 1.54 | 1.48 | 0.33 | no |
| PWM, 1 kg: 30° → −5° | 2.57 | 0.66 | 0.23 | yes |
| on/off (3 bar): 0° → 30° | 23.74 | 1.984 | 24.47 | no |
| on/off (3 bar): 30° → −5° | 30.02 | 1.996 | 13.4 | no |

PWM control

PWM control without load

PWM control without load, gain 1: it shakes

on/off control

## T7 load ratio

| Load (kg) | Load (%) | Overshoot (mm) | Settling (s) | Error (mm) | Passed |
|---|---|---|---|---|---|
| 1.0 | 24 | 1.54 | 1.48 | 0.33 | no |
| 2.0 | 46 | 2.09 | 0.556 | 0.43 | yes |
| 3.0 | 68 | 3.54 | 1.42 | 0.44 | no |
| 4.0 | 89 | 0.0 | 1.984 | 10.74 | no |
| 5.0 | 111 | 0.0 | 1.984 | 86.57 | no |

## T6 stiffness (valves closed, one 1 kg plate added)

| Sum of chamber pressures (bar) | Deflection (degrees) |
|---|---|
| 2.0 | 9.81 |
| 5.0 | 6.74 |

## T8 preset positions: smooth profile with feedforward

Load 1 kg (dumbbell plates bolted to the arm end), 5.0 bar. Targets 30°, -5°, 50°, 10°, 40°, 20° (the last two 0.15 s apart: a new target during a move). Criteria per move: tracking error < 3 mm, overshoot < 2 mm, within ±1.5 mm at most 0.2 s after the profile ends, mean error at rest < 1 mm. Worst case of 3 runs with different sensor noise.

| Move | Profile (s) | Tracking (mm) | Overshoot (mm) | Settled after the profile (s) | Command → settled (s) | Passed |
|---|---|---|---|---|---|---|
| → 30° | 0.404 | 1.12 | 1.14 | 0.0 | 0.404 | yes |
| → -5° | 0.432 | 0.99 | 1.37 | 0.0 | 0.432 | yes |
| → 50° | 0.584 | 1.29 | 1.13 | 0.0 | 0.584 | yes |
| → 10° | 0.452 | 1.37 | 0.91 | 0.0 | 0.452 | yes |
| → 20° | 0.672 | 1.03 | 23.79 | 0.0 | 0.672 | yes |

(one run; the last row is the new target during a move: its overshoot is past the new, nearer target and does not count)

T8

| Controller / setting | Tracking (mm) | Overshoot (mm) | Settled after the profile (s) | New target during a move: tracking (mm) | Passed |
|---|---|---|---|---|---|
| profile 170°/s, 1550°/s² (params.py) | 2.51 | 1.58 | 0.32 | 1.26 | no |
| 1.1× as fast (187°/s, 1876°/s²) | 3.0 | 2.41 | 0.048 | 1.58 | no |
| 1.15× as fast (195°/s, 2050°/s²) | 4.19 | 4.06 | 0.184 | 1.78 | no |
| 1.3× as fast (221°/s, 2620°/s²) | 4.34 | 5.06 | 0.212 | 4.75 | no |
| 2 kg load, same profile | 4.04 | 2.09 | 0.664 | 3.27 | no |
| 2 kg load, 10% lower speed | 3.31 | 1.43 | 0.0 | 2.12 | no |
| 2 kg load, 20% lower speed | 1.69 | 1.19 | 0.0 | 1.31 | yes |
| load set to 0.9 kg (real 1.0 kg) | 2.28 | 2.37 | 0.68 | 1.75 | no |
| load set to 1.1 kg (real 1.0 kg) | 2.03 | 1.56 | 0.936 | 1.44 | no |
| load set to 0.8 kg (real 1.0 kg) | 2.71 | 1.72 | 0.684 | 1.65 | no |
| load set to 1.2 kg (real 1.0 kg) | 1.69 | 1.51 | 0.32 | 1.27 | no |
| T3 controller (ramp 250 mm/s, no feedforward) | 19.6 | 6.21 | 0.324 | 19.65 | no |

T8 with the T3 controller

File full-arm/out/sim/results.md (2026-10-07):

# Light arm, stage 1 — dynamic simulation

Generated by `python full-arm/arm_sim.py`. Plan (moves only, no waiting): 20.2 s fast, 50.1 s controlled. Mean of 3 runs with different sensor noise. The gains are tuned for 1.5 kg and the same for every load, except in the rows marked “retuned”.

| Case | Time | Waiting in total | Longest wait | Largest lag while moving | Largest placement error | Air |
|---|---|---|---|---|---|---|
| 0.3 kg, elbow 2 × Ø25 (1b, fast) | 24.5 s | 4.3 s | 1.1 s | 39 mm | 2.6 mm | 10 l |
| 1.5 kg, elbow 2 × Ø25 (1b, fast) | 23.8 s | 3.6 s | 1.1 s | 44 mm | 3.0 mm | 10 l |
| 3 kg, elbow 2 × Ø25 (1b, fast) | 33.8 s | 13.6 s | 3.0 s (gave up) | 195 mm | 10.6 mm | 13 l |
| 3 kg, elbow 2 × Ø32 (1b, fast) | 30.7 s | 10.5 s | 3.0 s (gave up) | 199 mm | 29.9 mm | 21 l |
| 3 kg, elbow 2 × Ø32, retuned (1b, fast) | 31.0 s | 10.8 s | 3.0 s (gave up) | 289 mm | 19.3 mm | 21 l |
| 1.5 kg, elbow 2 × Ø25 (1a, controlled) | 53.5 s | 3.4 s | 1.2 s | 16 mm | 2.7 mm | 12 l |
| 3 kg, elbow 2 × Ø32, retuned (1a, controlled) | 56.8 s | 6.7 s | 1.7 s | 15 mm | 3.0 mm | 17 l |

Waiting = after a move down, until the gripper is within ±3 mm of its target and slower than 20 mm/s (at most 3 s, then it grips or releases anyway). Placement error = horizontal distance of the block from its place. Air in litres of free air.

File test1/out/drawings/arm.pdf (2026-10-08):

hinge Ø8.5; clevis Ø8.5; load Ø8.5

Arm — aluminium flat bar 40×5 mm, holes on the centre line; dimensions in mm

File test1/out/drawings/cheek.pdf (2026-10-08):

Ø22 × 7 deep (608 bearing) + Ø10 through; Ø8.5 through; Ø5 (block screw); holes at 20 and 45 high; back; front (arm)

Cheek — 2 pieces, plywood 18 mm Bearing seat on the OUTSIDE (mirror image for the second cheek) dimensions in mm

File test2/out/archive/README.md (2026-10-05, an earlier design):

# Archived renders

Renders of earlier test 2 layouts, kept for reference. The current renders are in `../`.

- `render_roll_90_*`: concept B with vertical cylinders under a hub 150 mm from the joint,
  roll 90° (commit b77ff19).
- `render_pitch_high_*`: right-angle layout (hub and lower pivots 220 mm from the joint,
  150 mm stroke), pitch 80° (commit d129595).

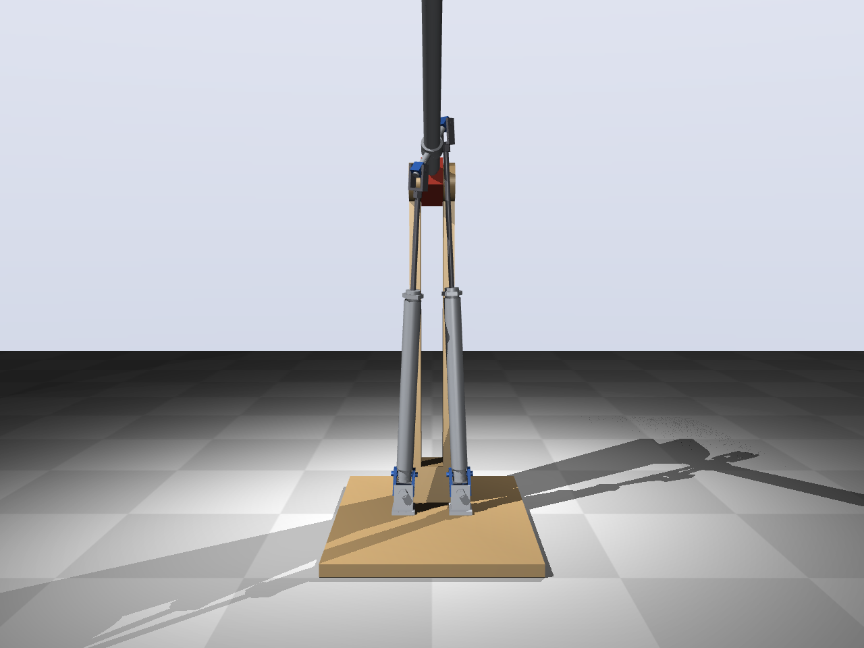
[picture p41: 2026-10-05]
test2/out/cross_block/render_pitch_up_roll_front.png

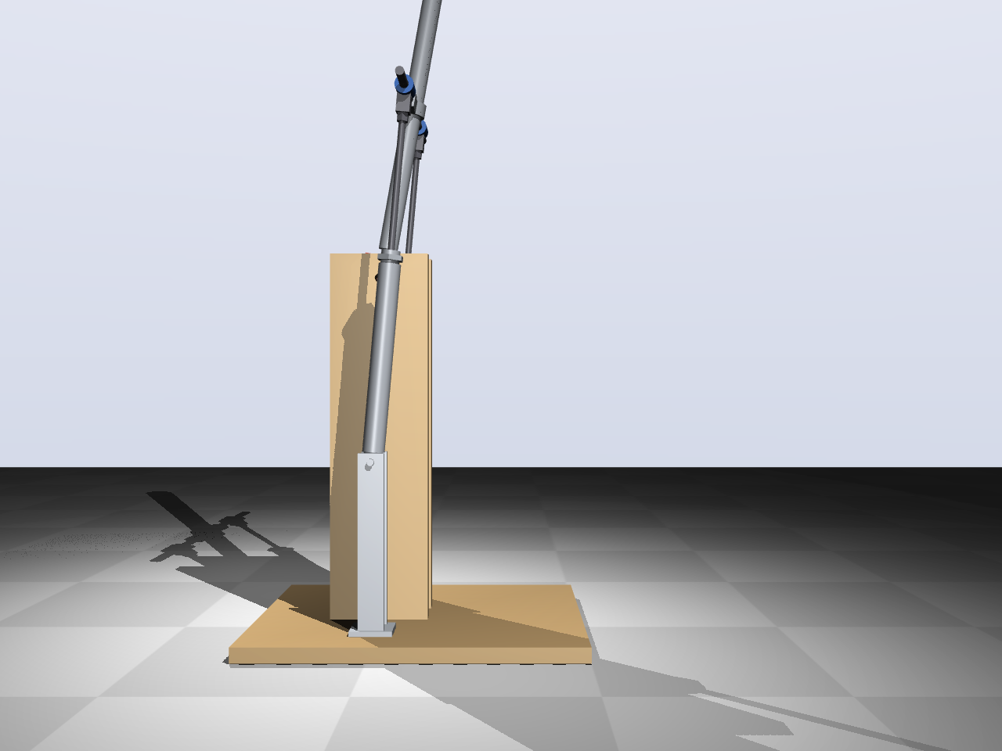
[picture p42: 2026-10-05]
test2/out/render_pitch_high_side.png

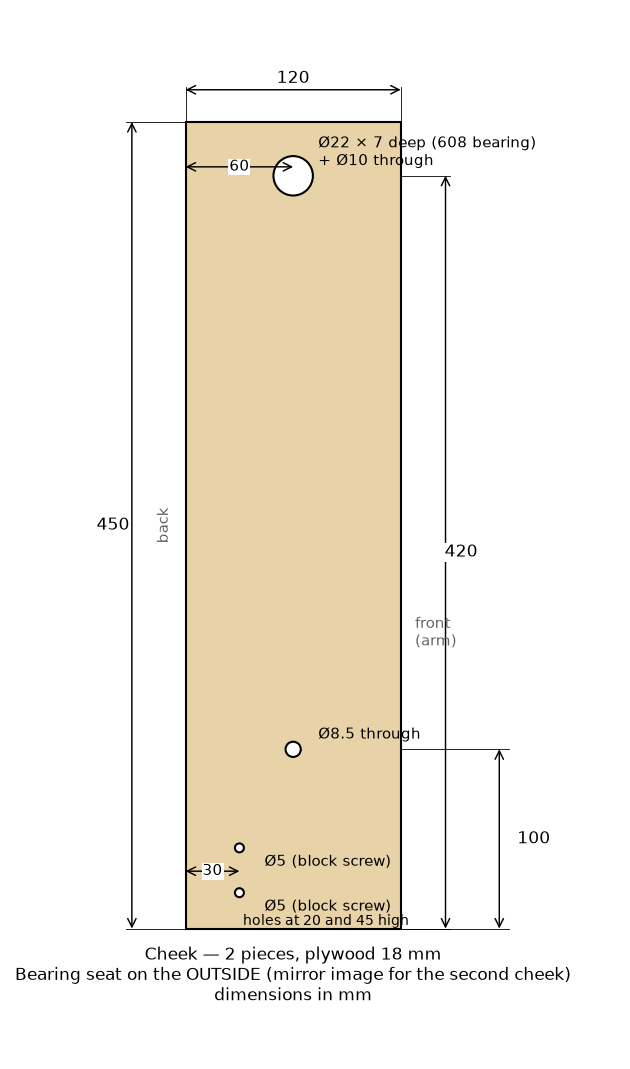
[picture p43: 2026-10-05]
test1/out/drawings/cheek.png

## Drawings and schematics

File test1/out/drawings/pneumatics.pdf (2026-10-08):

### Pneumatic diagram test 1

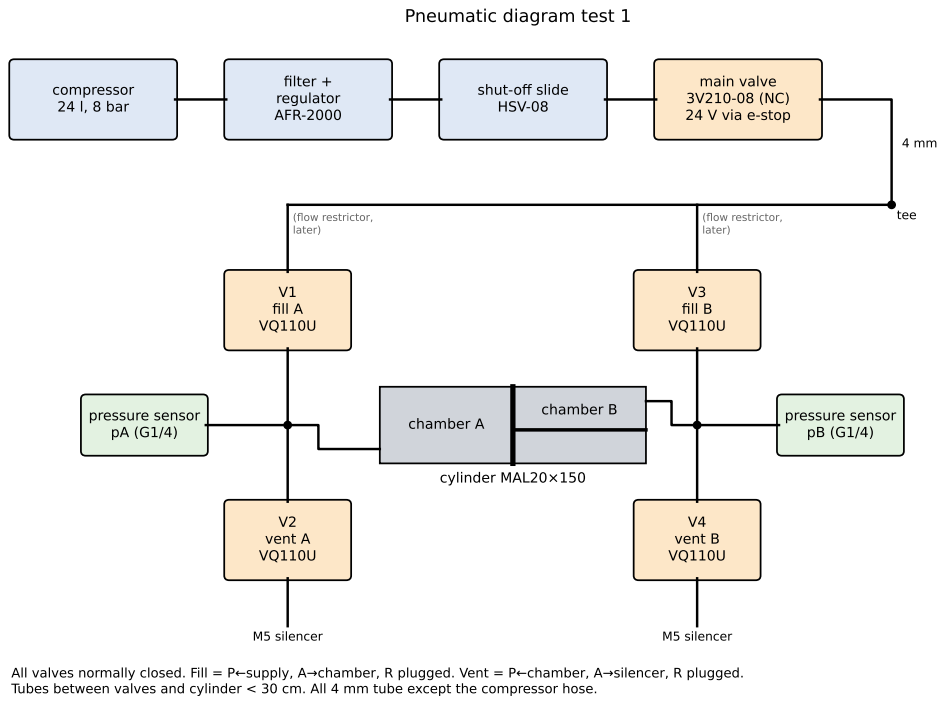
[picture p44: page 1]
compressor 24 l, 8 bar; filter +; regulator AFR-2000; main valve 3V210-08 (NC) 24 V via e-stop; (flow restrictor,; tee; later); V1 fill A; pressure sensor pA (G1/4); V2 vent A VQ110U; M5 silencer; V3 fill B; pressure sensor pB (G1/4); V4 vent B VQ110U; chamber A; chamber B; cylinder MAL20×150

shut-off slide
HSV-08

All valves normally closed. Fill = P←supply, A→chamber, R plugged. Vent = P←chamber, A→silencer, R plugged.
Tubes between valves and cylinder < 30 cm. All 4 mm tube except the compressor hose.

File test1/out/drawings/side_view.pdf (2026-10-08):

### Test 1 — side view (dimensions in mm)

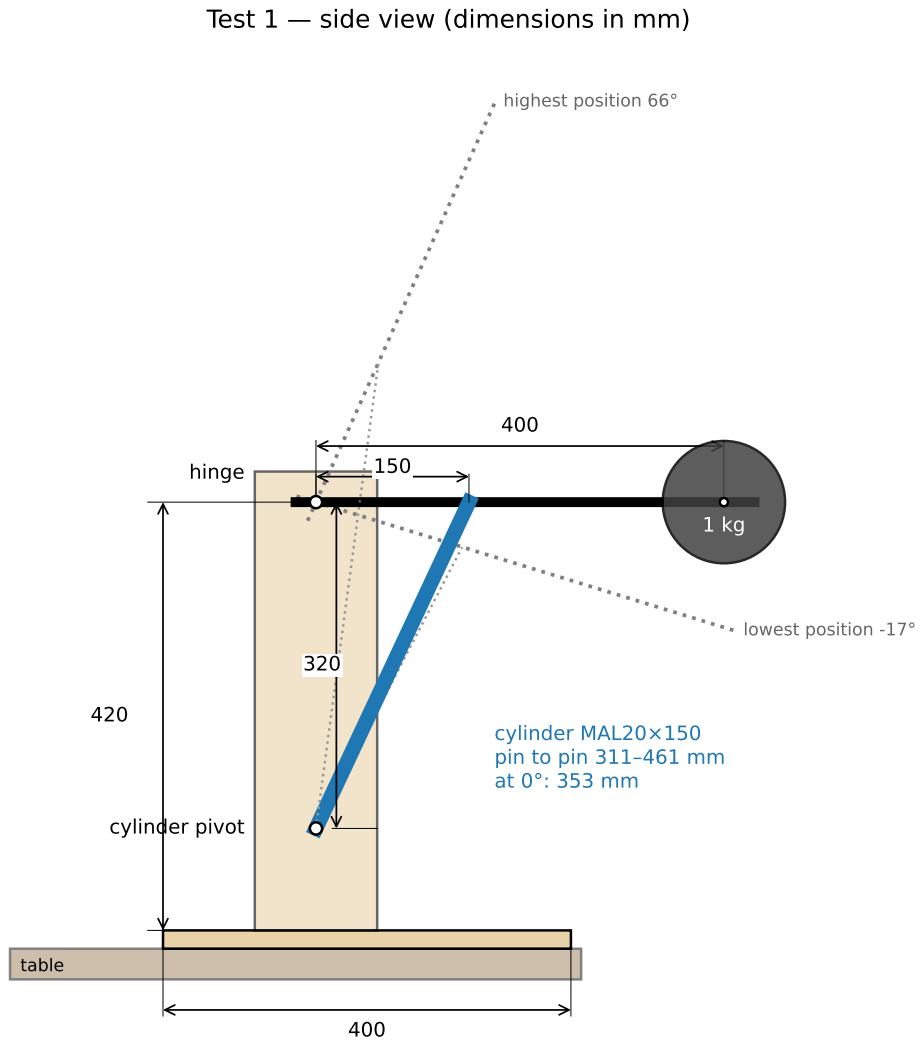
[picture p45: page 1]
table; lowest position -17°; highest position 66°; hinge; cylinder pivot

cylinder MAL20×150
pin to pin 311–461 mm

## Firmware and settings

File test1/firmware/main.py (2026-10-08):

"""Firmware for test 1: arm with one degree of freedom, pneumatic cylinder with 4 valves.

Control over USB (serial port, 115200 baud, lines of text). See the manual for all
commands; 'help' lists them too. The Pico sends data lines:
  D,time_ms,L_mm,angle_deg,pa_bar,pb_bar,fill_a,vent_a,fill_b,vent_b,mode,target_mm,fault,profile_mm
(profile_mm: where the target is now, along the profile of `move` or the ramp of `angle`)

Safety:
- After start-up and on every fault all valves are closed.
- If the Pico gets no message from the PC for longer than watchdog_ms while in an
  active mode (the PC sends 'ping'), all valves close.
- If the program hangs, the hardware watchdog resets the Pico (valves closed).
  The watchdog starts at the first motion command, so you can update the Pico with
  Thonny before that without it resetting.
- The emergency stop cuts the 24 V in hardware, independent of this software.
"""
import math
import select
import sys
import time

from machine import WDT

import control
from config import CFG
from hw import Sensors, Valves

valves = Valves(CFG["pins"], CFG["pwm_hz"])
valves.off()
sensors = Sensors(CFG)
ctl = control.Controller(CFG)
wdt = None   # hardware watchdog, started at the first active command (see start_watchdog)

poll = select.poll()
poll.register(sys.stdin, select.POLLIN)
line_buf = ""
last_msg = time.ticks_ms()
stream_every = max(1, CFG["loop_hz"] // 100)     # default about 100 data lines per second (125 at 250 Hz)
MOVE_LIMITS = (CFG["move_w_max"], CFG["move_alpha_max"], CFG["move_jerk_max"])   # at speed 1
GAINS = (CFG["kp_force"], CFG["ki_force"], CFG["kd_force"])                        # at gain 1
loop_stats = [0, 0, 0]      # steps, steps longer than the period, longest step (µs); shown and reset by 'info'


def angle(L):
    a, b = CFG["hinge_to_rear"], CFG["hinge_to_attach"]
    s = (L * L - a * a - b * b) / (2 * a * b)
    return math.degrees(math.asin(max(-1.0, min(1.0, s))))


def length(theta):
    a, b = CFG["hinge_to_rear"], CFG["hinge_to_attach"]
    return math.sqrt(a * a + b * b + 2 * a * b * math.sin(math.radians(theta)))


def start_watchdog():
    """Start the hardware watchdog. Once started it cannot be stopped: after stopping in
    Thonny the Pico resets itself within 2 s (with all valves closed)."""
    global wdt
    if wdt is None:
        wdt = WDT(timeout=2000)


def say(*parts):
    print(",".join(str(p) for p in parts))


def pulse_capture(channel, ms):
    """T1: open one valve for `ms` milliseconds and sample the pressure fast (≈ 5 kHz, 80 ms)."""
    valves.off()
    adc = sensors.adc_pa if channel in (0, 1) else sensors.adc_pb
    samples = []
    t0 = time.ticks_us()
    duty = [0.0, 0.0, 0.0, 0.0]
    duty[channel] = 1.0
    opened = False
    while time.ticks_diff(time.ticks_us(), t0) < 80_000:
        t = time.ticks_diff(time.ticks_us(), t0)
        if not opened and t >= 5_000:
            valves.set(duty)
            opened = True
        if opened and t >= 5_000 + ms * 1000:
            valves.off()
        samples.append((t, adc.read_u16()))
    valves.off()
    for t, v in samples:
        say("P", t, round(v / 65535 * 3.3 * sensors.div, 4))
    say("PEND", channel, ms)


HELP = """commands:
  off                         close all valves
  angle <deg>                 move the arm to an angle (position control)
  move <deg>                  move the arm to an angle fast and smoothly (profile + feedforward, T8)
  load <kg>                   load on the arm, for the feedforward of move
  speed <factor>              speed of move, 1 = as tuned (0.9 = 10% slower)
  gain <factor>               strength of the position control, 1 = as tuned (0.5 without load)
  pos <mm>                    move the cylinder to a pin-to-pin length
  bang <deg>                  on/off control (T2)
  pressure <pa> <pb>          control the chamber pressures (bar gauge)
  valve <fa> <va> <fb> <vb>   duty per valve 0..1 (manual)
  pulse <0-3> <ms>            open one valve briefly, sample the pressure fast (T1)
  stiffness <bar>             sum of the chamber pressures
  zero                        set the pressure sensors to 0 bar (no pressure on the cylinder!)
  cal_pressure <bar>          pressure sensor gain (both chambers at that pressure, see gauge)
  cal_pos in|out              potentiometer: cylinder fully in / fully out
  save                        store the calibration (cal.json)
  stream <hz>                 data lines per second (0 = off)
  info                        settings and calibration
  ping                        'still alive' from the PC"""


def handle(cmd):
    global stream_every
    p = cmd.split()
    if not p:
        return
    c = p[0]
    try:
        if c == "ping":
            return
        if c in ("angle", "move", "pos", "bang", "pressure", "valve", "pulse"):
            start_watchdog()
        if c == "off":
            ctl.set_mode(control.OFF)
        elif c == "angle":
            ctl.set_mode(control.POSITION, length(float(p[1])))
        elif c == "move":
            ctl.set_mode(control.MOVE, length(float(p[1])))
        elif c == "load":
            ctl.cfg["load_kg"] = float(p[1])
        elif c == "speed":
            k = float(p[1])
            if not 0.1 <= k <= 1.2:
                raise ValueError("speed between 0.1 and 1.2")
            w, al, j = MOVE_LIMITS
            ctl.cfg["move_w_max"], ctl.cfg["move_alpha_max"], ctl.cfg["move_jerk_max"] = w * k, al * k * k, j * k ** 3
        elif c == "gain":
            k = float(p[1])
            if not 0.2 <= k <= 1.5:
                raise ValueError("gain between 0.2 and 1.5")
            kp, ki, kd = GAINS
            ctl.cfg["kp_force"], ctl.cfg["ki_force"], ctl.cfg["kd_force"] = kp * k, ki * k, kd * k
        elif c == "pos":
            ctl.set_mode(control.POSITION, float(p[1]))
        elif c == "bang":
            ctl.set_mode(control.BANGBANG, length(float(p[1])))
        elif c == "pressure":
            ctl.set_mode(control.PRESSURE, (float(p[1]), float(p[2])))
        elif c == "valve":
            ctl.set_mode(control.MANUAL, tuple(float(x) for x in p[1:5]))
        elif c == "pulse":
            ctl.set_mode(control.OFF)
            pulse_capture(int(p[1]), float(p[2]))
        elif c == "stiffness":
            ctl.p_sum = float(p[1])
        elif c == "zero":
            _, va, vb = sensors.raw()
            sensors.cal["p_v_zero"] = [va, vb]
            say("OK", "zero", round(va, 4), round(vb, 4))
        elif c == "cal_pressure":
            bar = float(p[1])
            _, va, vb = sensors.raw()
            z = sensors.cal["p_v_zero"]
            sensors.cal["p_v_per_bar"] = [(va - z[0]) / bar, (vb - z[1]) / bar]
            say("OK", "cal_pressure", sensors.cal["p_v_per_bar"])
        elif c == "cal_pos":
            vpos, _, _ = sensors.raw()
            if p[1] == "in":
                sensors.cal["pot_v_retracted"] = vpos
            else:
                # fully out = full cylinder stroke (L_max - L_min)
                sensors.cal["pot_v_per_mm"] = (vpos - sensors.cal["pot_v_retracted"]) / (CFG["L_max"] - CFG["L_min"])
            say("OK", "cal_pos", p[1], round(vpos, 4))
        elif c == "save":
            sensors.save()
            say("OK", "save")
        elif c == "stream":
            hz = float(p[1])
            stream_every = 0 if hz <= 0 else max(1, int(CFG["loop_hz"] / hz))
        elif c == "info":
            say("INFO", CFG)
            say("CAL", sensors.cal)
            say("LOOP", "steps", loop_stats[0], "too_long", loop_stats[1], "longest_us", loop_stats[2])
            loop_stats[:] = [0, 0, 0]
        elif c == "help":
            print(HELP)
        else:
            say("ERROR", "unknown command", c)
            return
        say("OK", c)
    except Exception as e:  # noqa: BLE001 — bad input must not stop the loop
        say("ERROR", c, e)


def read_commands():
    global line_buf, last_msg
    while poll.poll(0):
        ch = sys.stdin.read(1)
        if ch in ("\n", "\r"):
            if line_buf:
                last_msg = time.ticks_ms()
                handle(line_buf.strip())
            line_buf = ""
        else:
            line_buf += ch


def pc_watchdog():
    """Close the valves if the PC sends nothing for too long while in an active mode."""
    if ctl.mode != control.OFF and time.ticks_diff(time.ticks_ms(), last_msg) > CFG["watchdog_ms"]:
        ctl.set_mode(control.OFF)
        say("ERROR", "no contact with the PC: valves closed")


def run():
    period_us = 1_000_000 // CFG["loop_hz"]
    t_next = time.ticks_us()
    t_last = t_next
    t_start = time.ticks_ms()
    n = 0
    say("OK", "started", "type 'help'")
    while True:
        t_loop = time.ticks_us()
        if wdt is not None:
            wdt.feed()
        read_commands()
        pc_watchdog()
        L, pa, pb = sensors.read()
        now = time.ticks_us()
        dt = time.ticks_diff(now, t_last) / 1e6      # real time since the last step (memory clean-up can pause the loop)
        t_last = now
        duty = ctl.update(min(max(dt, 1e-4), 0.05), L, pa, pb)
        valves.set(duty)
        n += 1
        if stream_every and n % stream_every == 0:
            ref = ctl.ref if ctl.ref is not None else 0.0
            prof = ctl.ref_now if ctl.ref_now is not None else ref
            d = valves.duty
            # % formatting: about 3× faster than joining str() of every field
            print("D,%d,%.2f,%.2f,%.3f,%.3f,%.2f,%.2f,%.2f,%.2f,%s,%.2f,%s,%.2f" % (
                time.ticks_diff(time.ticks_ms(), t_start), L, angle(L), pa, pb, d[0], d[1], d[2], d[3],
                ctl.mode, ref, ctl.fault, prof))
        busy = time.ticks_diff(time.ticks_us(), t_loop)
        loop_stats[0] += 1
        if busy > period_us:
            loop_stats[1] += 1
        if busy > loop_stats[2]:
            loop_stats[2] = busy
        t_next = time.ticks_add(t_next, period_us)
        wait = time.ticks_diff(t_next, time.ticks_us())
        if wait > 0:
            time.sleep_us(wait)
        else:
            t_next = time.ticks_us()


try:
    run()
finally:
    valves.off()

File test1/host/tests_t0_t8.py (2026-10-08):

"""Tests T0–T8 of test 1, run and assessed automatically.

    python tests_t0_t8.py T3 --port COM5
    python tests_t0_t8.py all --port COM5

Each test writes a folder results/<date>_<test>/ with the run (CSV), a plot (PNG) and
the outcome (JSON). Where you need to do something (set the pressure, hang a weight)
the script asks for it.
"""
import argparse
import json
import math
import os
import sys
import time

import numpy as np

import analysis
from pico import Pico

HERE = os.path.dirname(os.path.abspath(__file__))
sys.path.insert(0, os.path.join(os.path.dirname(HERE), "firmware"))
from config import CFG  # noqa: E402


def length(theta):
    a, b = CFG["hinge_to_rear"], CFG["hinge_to_attach"]
    return math.sqrt(a * a + b * b + 2 * a * b * math.sin(math.radians(theta)))


def ask(text):
    input(f"\n>>> {text}\n    Press Enter when ready... ")


def save(name, data, result, title=None):
    d = os.path.join(HERE, "results", time.strftime("%Y%m%d_%H%M%S_") + name)
    os.makedirs(d, exist_ok=True)
    if data is not None and len(data):
        np.savetxt(os.path.join(d, "run.csv"), data, delimiter=",", fmt="%.4f",
                   header="time_s,L_mm,angle,pa_bar,pb_bar,fill_a,vent_a,fill_b,vent_b,target_mm,target_pa,target_pb,profile_mm",
                   comments="")
        analysis.plot(data - np.r_[data[0, 0], np.zeros(data.shape[1] - 1)], os.path.join(d, "plot.png"), title or name)
    with open(os.path.join(d, "outcome.json"), "w") as f:
        json.dump(result, f, indent=2)
    print(json.dumps(result, indent=2))
    print(f"Saved in {d}")
    return result


def steps(p, plan, cmd="angle"):
    """Run (wait time, angle) steps and return the run and the step start times."""
    t_begin = p.now()
    marks = []
    for hold, theta in plan:
        p.send(f"{cmd} {theta}")
        marks.append((p.now() - t_begin, theta))
        p.wait(hold)
    data = p.take(since=t_begin)
    data[:, 0] -= t_begin
    return data, marks


def t0(p):
    ask("T0 leak test. Regulator at 3 bar, no plate on the arm.")
    p.send("gain 0.5")                          # softer control without load
    p.send("angle 20")
    p.wait(3)
    p.send("off")
    p.wait(0.5)
    t_begin = p.now()
    p.wait(60)
    d = p.take(since=t_begin)
    drop_a = float(np.mean(d[:20, 3]) - np.mean(d[-20:, 3]))
    drop_b = float(np.mean(d[:20, 4]) - np.mean(d[-20:, 4]))
    drift = float(np.max(np.abs(d[:, 1] - d[0, 1])))
    ok = max(drop_a, drop_b) < 0.1
    return save("T0_leak", d, dict(drop_a_bar=round(drop_a, 3), drop_b_bar=round(drop_b, 3),
                                   sag_mm=round(drift, 2), criterion="pressure drop < 0.1 bar in 60 s",
                                   passed=ok))


def t1(p):
    ask("T1 valves. Regulator at 3 bar.")
    res = {}
    for ch, name in enumerate(("fill_a", "vent_a", "fill_b", "vent_b")):
        if name.startswith("vent"):
            p.send("pressure 2 2")
            p.wait(2)
            p.send("off")
            p.wait(0.3)
        p.messages()
        p.send(f"pulse {ch} 10")
        p.wait(1.5)
        pts = [m.split(",") for m in p.messages() if m.startswith("P,")]
        t = np.array([int(x[1]) for x in pts]) / 1000.0     # ms
        v = np.array([float(x[2]) for x in pts])
        if len(t) < 10:
            res[name] = "no data"
            continue
        base = np.mean(v[t < 4.5])
        moved = np.where(np.abs(v - base) > 0.05)[0]
        delay = float(t[moved[0]] - 5.0) if len(moved) else float("nan")
        res[name] = dict(response_ms=round(delay, 2))
    ok = all(isinstance(r, dict) and r["response_ms"] < 10 for r in res.values())
    res["criterion"] = "pressure starts to change < 10 ms after the signal"
    res["passed"] = ok
    return save("T1_valves", None, res)


def t2(p):
    ask("T2 on/off control. Regulator at 3 bar.")
    data, marks = steps(p, [(3, 0), (3, 30), (3, -5)], cmd="bang")
    rest = {}
    for (t0_, th), (t1_, _) in zip(marks[1:], marks[2:] + [(data[-1, 0], None)]):
        sel = (data[:, 0] > t1_ - 0.5) & (data[:, 0] <= t1_)
        rest[f"to_{th}_deg"] = round(float(np.mean(np.abs(data[sel, 1] - length(th)))), 2)
    ok = all(v < 3 for v in rest.values())
    return save("T2_onoff", data, dict(deviation_mm=rest, criterion="comes to rest within ±3 mm",
                                       passed=ok), "T2 on/off control")


def t3_run(p, label):
    data, marks = steps(p, [(3, 0), (3, 30), (3, -5)])
    m1 = analysis.step_metrics(data, marks[1][0], marks[2][0], length(30))
    m2 = analysis.step_metrics(data, marks[2][0], data[-1, 0], length(-5))
    return save(label, data, dict(up_0_to_30=m1, down_30_to_minus5=m2,
                                  passed=m1["passed"] and m2["passed"]), label)


def t3(p, label=None):
    if label:                                   # T7: one run at the load that is on the arm
        p.send("gain 1")
        return t3_run(p, label)
    # first without load and with softer control (the tuning for 1 kg makes the light arm shake)
    ask("T3a PWM control without load. Regulator at 5 bar, no plate on the arm.")
    p.send("gain 0.5")
    a = t3_run(p, "T3a_pwm_no_load")
    p.send("off")
    ask("T3b PWM control with load: put one 1 kg plate on the arm. 5 bar.")
    p.send("gain 1")
    b = t3_run(p, "T3b_pwm_1kg")
    return dict(no_load=a["passed"], kg1=b["passed"], passed=a["passed"] and b["passed"])


def t4(p):
    ask("T4 repeatability. 5 bar, load 1 kg.")
    ends = []
    t_begin = p.now()
    for i in range(10):
        p.send(f"angle {-10 if i % 2 else 50}")
        p.wait(2.5)
        p.send("angle 20")
        p.wait(2.5)
        d = p.take(since=p.now() - 0.3)
        ends.append(float(np.mean(d[:, 1])))
    data = p.take(since=t_begin)
    data[:, 0] -= t_begin
    spread = (max(ends) - min(ends)) / 2
    return save("T4_repeatability", data, dict(end_positions_mm=[round(e, 2) for e in ends],
                                               spread_mm=round(spread, 2), criterion="spread < ±1 mm",
                                               passed=spread < 1.0), "T4 repeatability")


def t5(p):
    ask("T5 holding with load. 5 bar, load 1 kg (or heavier).")
    p.send("angle 30")
    p.wait(3)
    t_begin = p.now()
    p.wait(60)
    d = p.take(since=t_begin)
    d[:, 0] -= t_begin
    sag = float(np.max(np.abs(d[:, 1] - length(30))))
    return save("T5_hold", d, dict(max_deviation_mm=round(sag, 2), criterion="< 1 mm in 60 s",
                                   passed=sag < 1.0), "T5 hold")
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

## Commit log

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2026-10-03 Add design for test rig 1: one cylinder, four fast valves with PWM
2026-10-03 Explain how the VQ110 reaches 50 Hz PWM and correct its price
2026-10-03 Explain why the -M5 valve version is needed and describe the layered control
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2026-10-03 Add VQ110 flow rating and its replacement by the V100 series
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2026-10-04 Choose 3 standard and 2 large-flow VQ110 valves, large flow on the lifting direction
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2026-10-04 Add emergency stop with main valve, and fix how the cylinder is depressurised
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2026-10-04 Switch to five large-flow VQ110U valves, with flow restrictors to mimic smaller valves
2026-10-04 Turn the parts list into a full order list per shop, and switch to a ULN2803A driver with hardwired emergency stop
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2026-10-04 Pick a 175 mm pot and 100 psi G1/4 pressure sensors, power the sensors from a separate 5 V regulator
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2026-10-04 Add test T8 (two versus four valves) and a cost-per-DOF overview with possible savings
2026-10-04 Drop the two-valve option and clone savings: holding is a safety requirement; add pilot check valves for the arm
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2026-10-04 Match the cylinder port fittings to the cylinder's thread type (G/PT or NPT)
2026-10-04 Specify an ISO 6432 cylinder so the G1/8 ports are fixed by the standard
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2026-10-04 Switch straight push-in fittings to a per-piece listing that still has PC4-M5 and PC4-01
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2026-10-04 Replace loose e-stop plus box with an e-stop already mounted in a box
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2026-10-04 Replace the unavailable MP1584 step-down with a 7805 linear regulator for the sensor supply
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2026-10-04 Replace the stale parts tables with a summary that points to bestellijst.json; own 24 V adapter; silencers back in the connection plan
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2026-10-04 test1: generated CAD exports, sim meshes, plots and renders
    [afstandsblok.step, afstandsblok.stl, arm.step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]
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2026-10-04 test1: drawings (side view, cheek, arm, wiring schematic and list, pneumatic schematic); 36 mm cheek gap; mechanical parts and tools in the order list
    [afstandsblok.step, afstandsblok.stl, arm.step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]
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2026-10-04 test1: build script (regenerate everything, BOM, HTML docs, zip bundle, publish to the hosted folder)
    [stuklijst.csv]
2026-10-04 test1: regenerate CAD, drawings, simulation results and renders
    [afstandsblok.step, arm.step, beugel_potmeter.step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]
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2026-10-05 Translate all code to English: comments, firmware commands, PC tools, simulation, CAD and drawing labels
    Firmware commands are now angle, pos, bang, pressure, valve, pulse, stiffness, zero,
    cal_pressure, cal_pos, save, stream, info, ping and help.
    [afstandsblok.step, afstandsblok.stl, arm.step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]
2026-10-05 Translate the test1 manual, design document and README to English; BOM is now docs/bom.md
    [bom.csv]
2026-10-05 Regenerate CAD, drawings, simulation results and renders with English names and labels
    [arm.step, arm.stl, arm_profile.dxf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]
2026-10-05 Allow 3× 47 kΩ in parallel instead of 15 kΩ in the pressure sensor divider
    [bom.csv]
2026-10-05 Record the electronics order (Tinytronics, Pico 2W, 10k + 3×47k dividers)
    [bom.csv]
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2026-10-05 Record the compressor order: Stanley DST 100/8/6 instead of the Parkside
    [bom.csv]
2026-10-05 test2: first concept of the 2-DOF joint (universal joint, two cylinders on a crossbar) with CadQuery model and renders
    [test2_concept.step]
2026-10-05 test2: concept B — hub with two hinged bars, vertical cylinders with sliding sleeves (roll up to ±90°)
    [test2_concept.step]
2026-10-05 test2: inclined cylinders with pivots behind the upright — pitch −40…+50°, roll ±65°, collision check
    [test2_concept.step]
2026-10-05 test2: right-angle layout — hub and lower pivots both 220 mm from the joint, retracted length x·√2; pitch 0…85° with roll ±65°
    [test2_concept.step]
2026-10-05 test2: taller stand, 200 mm stroke cylinders standing upright under the hub — pitch −45…+75° with roll ±65°
    [test2_concept.step]
2026-10-05 test2: cross block variant — fixed bar on the hub, turning block and rod fork form a universal joint, so the rods carry no bending
    [test2_concept.step]
2026-10-05 test2: cross block variant gets a bottom universal joint (y pin through the rear eye, fork swinging on an x bolt) instead of a rod end
    [test2_concept.step]
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2026-10-06 test1-cycloid: printed PLA cycloidal drive (24:1, steel pins) for the test 1 arm, sharing the motor with the harmonic drive reference; CAD, clash check, renders, STL
    [cam.stl, carrier_front.stl, carrier_rear.stl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]
2026-10-06 test1-cycloid: STEP export (per printed part and coloured assembly); disc outline as a spline instead of a polyline
    [assembly.step, cam.step, carrier_front.step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]
2026-10-06 test1-cycloid: print fits as parameters (bearing seats +0.15, pegs −0.10, pins +0.10), shoulder clears the 6808 inner ring, fit test plate to tune them first
    [assembly.step, cam.step, cam.stl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]
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2026-10-06 docs: correct hydraulic valves — SV3-10-C is an on/off cartridge, not proportional; proportional cartridges (SP08-20, EHPR98) cost about €100, so hydraulics is about €450–600 per DOF
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2026-10-06 test1: bill of materials — compressor received
    [bom.csv]
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2026-10-06 full-arm: elbow-down triceps cylinders shorter (compact Ø50 × 160) and closer to the elbow (rear pivots 15 cm from the shoulder)
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2026-10-07 Small wall: gripper proposal (MGN12, rack-and-pinion jaws, Ø16 cylinder); stage 1b is about compensating overshoot
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2026-10-07 Electronics (Tinytronics) received; incoming inspection rows for Pico, resistors, capacitors
    [bom.csv]
2026-10-07 full-arm: yaw axis through the shoulder joint, column behind it on the turntable
    The column turns with the base and carries the shoulder joint on an arm over the
    top; the shoulder cylinders' lower pivots sit on a pin through the column. The
    stack moves to 0.58 m from the yaw axis so the arm reaches it in the same poses
    as before (further away the picks oscillate in the simulation). Side render added.
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2026-10-08 order list: T8 knob and button (MCP3208 ADC, potentiometer, push button)
    [bom.csv]
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2026-10-08 test1: load is 1 kg dumbbell plates bolted to the arm end instead of a hanging bottle
    Base load 1 kg (one plate) for T0–T6 and T8; T7 in 1 kg steps up to 5 kg; T6 adds
    a plate. The plates cannot swing, so the simulation has no pendulum any more. With
    the current tuning T3 and T8 pass at 1 kg; at 2 kg T8 passes at 90% speed. CAD,
    drawings, renders, simulation, manual, design, test script and order list updated.
    [arm.step, base_plate.step, bom.csv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]
2026-10-08 test1 T8 with preset angles; firmware at 250 Hz as measured on the Pico
    - T8 without a knob: the test script sends preset angles with move; the assessment
    (analysis.t8_metrics) is shared by the simulation and the real test
    - firmware: commands move, load, speed; profile position in the data lines; loop
    statistics in info; the controller gets the real elapsed time per step
    - measured on the Pico 2 W: a step takes about 2 ms, so the loop runs at 250 Hz;
    data lines with % formatting (0.5 instead of 1.6 ms); the profile is computed
    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
    [arm.step, base_plate.step, bom.csv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]
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2026-10-10 Revert the pre-fill before the first move: it hid the jump instead of removing it
    The pre-fill kept the target at the arm while filling, so the jump off the end stop
    (5–20 mm in the simulation: chamber A is only dead volume there and one valve pulse
    adds 1–2 bar) was not counted as a tracking error. Reverted until the cause is fixed.
    This reverts commit a57d512.
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2026-10-10 test1 load: M8 threaded rod for up to 5 plates, washers sized to the plate's hole
    The M8×60 bolt was too short for T7 (5 plates need about 95 mm). Washers must be
    at least 10 mm wider than the plate's hole; plywood discs for 50 mm holes.
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
